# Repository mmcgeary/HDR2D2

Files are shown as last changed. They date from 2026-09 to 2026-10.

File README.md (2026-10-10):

# Home Depot R2-D2 Conversion

An in-progress build to turn the 2024 Home Depot R2-D2 animatronic into a fully remote-controlled droid with upgraded lights, sound, dome movement, and powered feet.

The build keeps the stock exterior shell while adding:
* **AstroPixels lighting:** Logic displays (FLD/RLD), process state indicators (PSIs), and 3 illuminated holoprojectors.
* **Split controllers:** Teensy 4.1/Treedix in the body for radio, feet, dome rotation and audio; AstroPixels ESP32 in the dome for lighting, six holo servos, Hall input, Wi-Fi and choreography.
* **Onboard sound:** DFPlayer Mini, 12V Class-D amplifier, and speaker firing through the front acoustic vents for chatter and movie sounds.
* **Dual-motor foot drive:** Razor Tekno Pop hub motors in the feet powered by a Flipsky Dual FSESC 4.20 motor controller.
* **FlySky radio control & Wi-Fi:** 10-channel RC control, plus an onboard Wi-Fi dashboard for triggering routines, adjusting volume, and flashing firmware updates.
* **Clean power harness:** 12V LiFePO4 battery, master cutoff switch, fused branch circuits, and dedicated 5V power converters for the body and dome.

---

## Quick Reference

**Approved split controller architecture:** Teensy 4.1 in the body handles radio decoding, dual VESC UART control, continuous dome servo, and DFPlayer audio. AstroPixels Plus ESP32 in the dome manages lighting (ReelTwo), holo servos, Hall reference sensors, Wi-Fi dashboard, and wireless `/commissioning` Web UI.

| Guide | Description |
| :--- | :--- |
| [System Architecture](SYSTEM_ARCHITECTURE.md) | High-level system overview, subsystem descriptions, and block diagrams |
| [Body Controller Wiring](BODY_CONTROLLER_WIRING.md) | Authoritative Teensy/Treedix terminal map, receiver, selected shifters and UART harnesses |
| [Commissioning](BODY_CONTROLLER_COMMISSIONING.md) | Wireless `/commissioning` UI workflow, USB isolation, and subsystem/failure checks |
| [Power Harness Guide](POWER_HARNESS_GUIDE.md) | Wire gauges, fuse sizes, crimping standards, and step-by-step electrical testing |
| [Interactive Wiring Diagram](wiring_visualizer.html) | Searchable terminal-to-terminal wiring schematic (open locally in your browser) |
| [System Wiring Overview](DOME_WIRING_DIAGRAM.md) | Logical circuit diagrams, slip-ring assignments, and logic-level shifter pinouts |
| [AstroPixels Plus Firmware Guide](ASTROPIXELS_PLUS_UNIFIED/README.md) | Dome firmware setup, target pin map, sound files, Web UI, and safety controls |
| [Teensy Body Controller Guide](TEENSY_BODY_CONTROLLER/README.md) | Teensy firmware architecture, scheduler, CLI commands, and test suites |
| [VESC Drive Setup](VESC_DRIVE_INTEGRATION.md) | Motor detection, current limits, radio mixing, and safety failsafes for the feet |
| [Controller Operator Guide](CONTROLLER_OPERATOR_GUIDE.md) | Switch/stick layout, dial routines, and safe power-on checklist for the FlySky transmitter |
| [Bill of Materials](Master_R2D2_BOM.xls) | Complete parts list, hardware links, and purchase notes (Excel-compatible) |

Use the body guide for pins and the power guide for fuses. `ESP32_DOME_BRAIN_GUIDE.md` and standalone sketches are historical references, not alternative instructions for the selected hardware.

---

## Repository Contents

### Primary Firmware
* [`TEENSY_BODY_CONTROLLER/`](TEENSY_BODY_CONTROLLER/): PlatformIO firmware for the Teensy 4.1 body controller. Manages radio input, dual-motor VESC control, dome servo positioning, DFPlayer audio, and commissioning calibration state machine.
* [`ASTROPIXELS_PLUS_UNIFIED/`](ASTROPIXELS_PLUS_UNIFIED/): PlatformIO ESP32 firmware built on AstroPixels Plus/ReelTwo. Manages dome lighting, holo servos, Hall reference inputs, Wi-Fi dashboard, `/diagnostics` telemetry, and wireless `/commissioning` Web UI.
* [`shared/R2BodyLink/`](shared/R2BodyLink/): Shared wire protocol codec and packet framing for the bi-directional SLIP link between body and dome.
* [Firmware implementation plan](docs/superpowers/plans/2026-10-09-teensy-firmware.md): Comprehensive 12-task architecture and verification plan.

### Operation & Radio Control
* [`CONTROLLER_OPERATOR_GUIDE.md`](CONTROLLER_OPERATOR_GUIDE.md): Illustrated FlySky FS-i6X transmitter layout, detailed control breakdown, 13-routine dial schedule, and power-on safety checklist.

### Wiring & Power
* [`POWER_HARNESS_GUIDE.md`](POWER_HARNESS_GUIDE.md) and [`DOME_WIRING_DIAGRAM.md`](DOME_WIRING_DIAGRAM.md) detail the entire electrical layout, wire sizes, fusing, and testing steps.
* [`wiring_visualizer.html`](wiring_visualizer.html) is an interactive offline wiring inspector with a printable wire schedule.

### Mechanical Files & Models
* [`index.html`](index.html), `app.js`, and `styles.css`: Mechanical visualizer for exploring foot-drive clearance and design concepts.
* [`Razor_Hub_Motor_Slotted_Mount.stl`](Razor_Hub_Motor_Slotted_Mount.stl) & [`generate_slotted_mount_stl.py`](generate_slotted_mount_stl.py): 3D-printable slotted motor mount and generator script.
* [`mechanical/tekno-pop-motor-mounts-wip/`](mechanical/tekno-pop-motor-mounts-wip/): Work-in-progress 3D models for mounting Razor Tekno Pop scooter hub motors into the droid feet:
  - [`r2d2_clean_motor_mount.stl`](mechanical/tekno-pop-motor-mounts-wip/r2d2_clean_motor_mount.stl)
  - [`r2d2_inboard_axle_keeper_plate.stl`](mechanical/tekno-pop-motor-mounts-wip/r2d2_inboard_axle_keeper_plate.stl)
  - [`case_bottom_locators_only.stl`](mechanical/tekno-pop-motor-mounts-wip/case_bottom_locators_only.stl)
  Check dimensions, fit, and print orientation before final assembly.

### Alternative & Reference Code
* `ASTROPIXELS_UNIFIED_BRAIN.ino` and `ESP32_DOME_BRAIN_GUIDE.md`: Earlier FastLED-based alternative firmware. Kept for reference; do not mix with the PlatformIO build.
* `Dome_Control_with-Audio-Nano2-Body.ino`: Earlier Arduino Nano reference sketch for sound coordination.
* [`tests/`](tests/): Host-side Python unit tests that verify firmware timing contracts, macro behavior, and wiring diagram routes.

---

## Build Safety & Testing Steps

To avoid damaging electronics or running into wiring issues, test your build in stages:

1. **Inspect wiring unpowered:** Check crimps, wire gauges, and screw terminals with a multimeter for shorts before connecting any power.
2. **Verify power rails:** Power the 12V bus through the main fuse and verify voltage at each buck converter input. Check that both buck converters output a clean 5.0V before connecting any boards.
3. **Keep 5V rails separate:** The body and dome each use an independent 5V buck converter. **Never connect their +5V outputs together.** Common ground connects everywhere.
4. **Flash the ESP32 unmounted:** Remove the ESP32 module from the AstroPixels dome motherboard before plugging into your computer via USB. Reinstall it only with all power turned off.
5. **Elevate wheels during motor tests:** When configuring the Dual VESC or testing radio transmitter mixes, always elevate the droid so the wheels can spin freely in the air.
6. **Set up radio failsafes:** Test transmitter-off and unplugged receiver separately; CH6 must go OFF. Record actual stopping distance and each VESC's timeout brake action.
7. **Accessible master cutoff:** Keep the 25A main battery fuse close to the battery (<=150mm), and mount the master power switch where you can hit it instantly from the outside.

---

## Upstream Software & Community Credits

* **[AstroPixels Plus](https://github.com/reeltwo/AstroPixelsPlus)** (maintained by the ReelTwo team) is the foundation for `ASTROPIXELS_PLUS_UNIFIED/`. It provides the Wi-Fi dashboard, settings storage, lighting animations, and web interface. Licensed under LGPL-2.1.
* **[AstroPixels](https://github.com/dpoulson/Astropixels)** (by David Poulson) provides the original AstroPixels display board designs and core firmware. [Official Documentation](https://r2djp.gitbook.io/astropixels).
* **[ReelTwo](https://reeltwo.github.io/Reeltwo/html/index.html)** provides the underlying robotics, lighting, and animation framework used across the astromech builder community.
* **[The Real Home Depot R2D2 Mods Group](https://www.facebook.com/groups/969844001468804)** is the community hub for 3D-printable parts, reinforcement ideas, and conversion guides.

This is an independent hobbyist build, not affiliated with or endorsed by Home Depot, Lucasfilm, or Disney.

---

## Upstream Comparison: Why AstroPixels Plus?

We reviewed the standard AstroPixels firmware (`src/standard/main.cpp`) alongside AstroPixels Plus to decide which base to use for this project:

| Feature | Standard AstroPixels | AstroPixels Plus (Selected) | Notes for this Build |
| :--- | :--- | :--- | :--- |
| **User Interface** | Serial / I2C commands only | Built-in Wi-Fi dashboard & web GUI | Plus gives us an easy phone/browser dashboard to trigger sounds, test macros, and adjust settings. |
| **Remote Control** | Serial2 (9600 baud) or I2C slave | Body client on Serial2 (115200 baud) | Reserved GPIO16/17 for the bidirectional body link; radio/drive/audio handled by Teensy. |
| **Firmware Updates** | USB cable required | Wireless ArduinoOTA & web uploads | Gated by body maintenance-lock acknowledgement before either OTA path writes flash. |
| **Lighting Effects** | ReelTwo display classes & sequences | ReelTwo display classes & sequences | Both firmware families use the same high-quality ReelTwo lighting engines. |
| **Library Versions** | Unpinned dependencies | Pinned PlatformIO environment (`esp32@5.2.0`, `ReelTwo@23.5.3`) | Pinned dependencies ensure consistent, reliable builds without unexpected breakage from newer library versions. |

AstroPixels Plus gives us the web dashboard, OTA updating, and flexible serial setup we need without losing any lighting features.

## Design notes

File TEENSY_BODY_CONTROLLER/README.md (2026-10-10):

# Teensy body controller

Commissioning-first PlatformIO target for the Teensy 4.1 body controller
(see `docs/superpowers/specs/2026-10-09-teensy-body-controller-design.md`).

## Architecture & Executive Scheduler

The body executive is coordinated by `body::BodyController` (`src/body/BodyController.{h,cpp}`):
- **Deterministic non-blocking scheduler:**
  - Receiver sensor processing first (micros-accurate IBUS telemetry sensor response).
  - Bounded UART pump drains (at most 96 bytes per full-duplex port per pass).
  - Drive control updates on a 20ms cadence with paired wheel command dispatch.
  - VESC duplex telemetry polling at 100ms per wheel; raw diagnostic capture support.
  - RC snapshot updates and periodic `BODY_STATUS` publishing (200ms) and `AUDIO_STATUS` (500ms).
  - Watchdog supervision via `Watchdog_t4` (`WDT_T4<WDT1>` with 1.0s timeout) fed only when the previous scheduling pass took <=50ms.
- **Subsystem Orchestration:**
  - `DriveController`: Dual-wheel VESC mixing, ramp slew, reversal dwell, and failsafe braking.
  - `DomeController`: Continuous servo positioning, RC manual steering, drive-follow biasing, and Hall tracking.
  - `DomeCalibration`: Wireless commissioning state machine executing neutral trim, reference alignment, and 3-revolution CW/CCW rate calibration with keepalive and radio safety guards.
  - `DfPlayer`: Serial MP3 player interface with acknowledged track dispatch and completion event tracking.
  - `LinkEndpoint`: Shared SLIP protocol framing over Serial4 connecting to the ESP32 dome head.

## Control Epoch & Maintenance Locks

To guarantee safe coordination between local RC inputs and remote commands:
- **Motion Locks:** All physical motion (drive and dome) is inhibited when `motionLocked()` is true.
  - Lock bit 0 (value 1): STOP latched (`STOP_ALL`, or operator `LOCK`). Released by `RELEASE_STOP`/operator `UNLOCK`.
  - Lock bit 2 (value 4): Maintenance Lock (`LOCK` operation with explicit non-zero token). Released by `UNLOCK` with that token.
  - CH6 OFF is not a lock: it simply disarms the feet.
  - Releases are all-or-nothing and require fresh RC, CH6 OFF and sticks centred 500ms; a refused release (`NotReady`) changes nothing. `RECOVER_LOCKS` clears both bits behind the same gate.
- **Epoch Tracking:** Any state change (`STOP_ALL`, `RELEASE_STOP`, `LOCK`, `UNLOCK`, `RECOVER_LOCKS`) increments `control_epoch`. Stale motion commands carrying an older epoch are rejected with `Result::WrongEpoch`.
- **Commissioning-First Safety:** Actuators run only the *saved* profile (`activeProfile()`); edits are staged until Save, which applies without a reboot. The dome servo gets no pulses until servo neutral is accepted and saved; the feet stay disarmed until all eight VESC sign-offs are accepted and saved.

## USB Line CLI

The controller provides an interactive, bounded line-based USB serial CLI:
- `status`: Displays current drive state, motion locks, control epoch, faults, and voltages.
- `rc`: Displays latest radio input snapshot (channels 1-14, age, validity).
- `vesc`: Displays left and right VESC RPM, duty, current, and voltage.
- `profile show`: Shows saved and staged readiness and acceptance masks, plus the staged servo neutral and auto speed.
- `profile set FIELD VALUE [WHEEL]`: Stages one profile field (`profile save` to apply). Same path and gate as the wireless SetField: fresh RC, CH6 OFF, sticks centred, no motion lock and no test running or braking out. CH9 (SwD) may be in either position.
- `profile save`: Persists the staged profile to EEPROM and makes it the active profile immediately (no reboot).
- `profile accept BIT`: Accepts a sign-off bit by name (`servo_neutral`, `front_reference`, `rear_reference`, `auto_timing`, `vesc_config_left`/`_right`, `timeout_brake_*`, `direction_*`, `reversal_*`), with the same evidence rules and gate as the wireless page (fresh RC, CH6 OFF, sticks centred, no motion lock, no test running). `timeout_brake_*`, `direction_*` and `reversal_*` need that wheel's passed automated wheel test, run from the `/drive` page.
- `profile baseline`: Stages the recommended baseline into every **unset** field (servo trims, auto speed, slew, VESC layout/currents/voltages/timeout/brake/reversal, and each wheel's firmware as observed over its UART). It never overwrites a set field and never accepts a bit; `profile save` to apply. Same gate as `profile accept`.
- `profile enable`: Reports the saved profile's readiness (drive, manual dome, auto dome); it does not change anything.
- `stop`: Immediately latches emergency stop and stops all actuators.

## Testing

Host unit tests compile Teensy controller sources directly with native clang/g++:

```bash
python3 -m unittest discover -s tests -p "test_body_*.py" -v
python3 -m unittest discover -s tests -p "test_dome_*.py" -v
```

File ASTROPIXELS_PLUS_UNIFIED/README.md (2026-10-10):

# AstroPixels Plus Unified: Dome Firmware and Target Wiring

> **Safety Notice:** Do not connect this wiring to the old ESP32-only firmware. Flash both the Teensy 4.1 body controller and the AstroPixels Plus ESP32 with the current firmware before combined testing; nothing counts as bench-verified until the commissioning record is filled in.

This firmware runs on the ESP32 in the dome for lighting (ReelTwo), Wi-Fi, holo servos, Hall reference sensors, sound selection, and web-based diagnostics/commissioning. All radio decoding, motor drive, continuous dome-servo pulsing, and DFPlayer UART ownership are handled by the Teensy body controller.

Follow [Body Wiring](../BODY_CONTROLLER_WIRING.md), [Dome Wiring](../DOME_WIRING_DIAGRAM.md) and [Commissioning](../BODY_CONTROLLER_COMMISSIONING.md).

## 1. Target ESP32 map

| ESP32 pin | Target role |
| --- | --- |
| GPIO16 | Serial2 RX, body link from TeensyTX17 via ringCH3 |
| GPIO17 | Serial2 TX, body link to TeensyRX16 via ringCH6 |
| GPIO18 | Rear Hall signal through dome Lonely Binary channel 3 |
| GPIO19 | Front Hall signal through dome Lonely Binary channel 2 |
| GPIO21/22 | PCA9685 SDA/SCL |
| GPIO15/33 | FLD/RLD |
| GPIO32/23 | FPSI/RPSI |
| GPIO25/26/27 | FHP/RHP/THP LEDs |
| GPIO2/4/5 | Unused / spare |

Serial2's sole reader is the framed body client at 115200; the old MarcDuino UART reader has been disabled while web/internal commands remain. Receiver, VESCs, continuous dome-servo pulses and DFPlayer UART are handled by Teensy.

| Contact | BODY end | DOME end | Function |
| --- | --- | --- | --- |
| CH1 | F4 7.5A fused battery positive | Dome buck IN+ | Dome 12V feed |
| CH2 | Body ground bus | Dome ground / buck IN- | Common return |
| CH3 | Teensy TX17 | ESP32 GPIO16 | Body to dome serial |
| CH4 | Unconnected | Unconnected | Spare |
| CH5 | Unconnected | Unconnected | Spare |
| CH6 | Teensy RX16 | ESP32 GPIO17 | Dome to body serial |

UART 3.3V bypasses shifters. Dome Lonely Binary HV=D-LOGIC 3A fused 5V, LV=ESP32 3.3V, GND common; Front Hall HV2->LV2->GPIO19, Rear Hall HV3->LV3->GPIO18. No receiver signal in dome.

PCA9685 VCC=3.3V, V+=D-SERVO 5A fused 5V with 16AWG feed/return; AstroPixels I2C D/C/G ->SDA/SCL/GND, V unconnected. Address 0x40,50Hz;0/1front pan/tilt,2/3rear,4/5top.

## 2. Target radio controls and safety

| Input | Target function |
| --- | --- |
| CH1 / right horizontal | Foot steering |
| CH2 / right vertical | Foot throttle |
| CH3 / left vertical | Unused |
| CH4 / left horizontal | Manual dome rotation |
| CH5 / SwC (3-pos) | Normalized duty rates35/70/100%;95% absolute cap |
| CH6 / SwA | Drive enable; OFF -> ON -> centered 500ms after boot/fault |
| CH7 / VrA + CH8 / SwB | Macro selection / trigger |
| CH9 / SwD | Auto Dome enable |
| CH10 | Unused |

Teensy validates RC, both VESC feedback links and actuator locks. Stale/faulted feedback on either wheel inhibits both; neutral uses brake current, not zero duty. Manual dome can work with CH9 OFF; automatic home requires fresh RC, CH9 ON and neutral dome stick.

Wi-Fi STOP latches a body stop and displays verified body confirmation or "Body stop unconfirmed"; **Release STOP** clears it once CH6 is OFF and the sticks are centred. Routine actions (Prepare update, commissioning tests, RC loss) never latch a body stop. Maintenance locks remain latched across dome restart; Faint macro does not engage maintenance lock. ArduinoOTA and web uploads are aborted unless the body maintenance lock is held. The `/commissioning` page stages profile fields, reads them back and accepts every sign-off bit (0-11).

## 3. Sound library and choreography

Keep FAT32 microSD folder `/01/`, three-digit filenames. Ambient chirps/chatter use 001-080; macro tracks stay reserved. Default volume 10/30 unless saved settings override it; no physical volume potentiometer required.

| VrA position / command | Track | Intended routine |
| --- | --- | --- |
| 1 / `:DMH` | 011.mp3 | Home dome, then sound |
| 2 | Random | Normal / cheerful |
| 3 | Random | Normal / happy |
| 4 / `:SE01` | 102.mp3 | Scream / alarm 4.5s |
| 5 / `:SE05`, `:SE07` | 106.mp3 | Cantina lights and holo dance 30s |
| 6 / `:SE08` | 109.mp3 | Leia: home first, then playback-confirmed choreography 14s |
| 7 / `:SE09` | 110.mp3 | Disco 20s |
| 8 / `:SE06` | 107.mp3 | Faint / motion lock 5s |
| `:DMS`, `:SE00` | None | Stop |
| Startup | 255.mp3 | Startup chime |

Folder-play command 0x0F uses `/01/`. Supply your own legally obtained audio. ESP32 selects tracks while Teensy controls the DFPlayer and returns playback events; an accepted UART request alone does not prove audible sound.

## 4. Wi-Fi & Web Pages

SSID **AstroPixels**, password **Astromech**, dashboard **http://192.168.4.1**.
- **Main Dashboard (`/`):** Logic and PSI text controls, LED colours/speed, sound volume, manual and autonomous macros, and acknowledged emergency STOP.
- **Diagnostics (`/diagnostics`):** Real-time display of radio channels, VESC left/right status (voltage, current, eRPM, faults), body faults, lock reasons, and link latency.
- **Commissioning (`/commissioning`):** Dedicated calibration page for continuous dome servo and Hall sensors without requiring a laptop/USB tether. Provides live Hall Front/Rear readouts, RC snapshot, test controls (`Neutral`, `Front Ref`, `Rear Ref`, `Timing CW`, `Timing CCW`), emergency `Cancel Test`, acceptance bitmask, and `Save Profile` to Teensy EEPROM.
- **Firmware Upload (`/upload`):** Web and ArduinoOTA update portal gated by explicit body maintenance-lock handshake.

## 5. First bare ESP32 flash

Turn off/disconnect droid power. Remove ESP32 from AstroPixels **before** USB. Use a data cable matching the module's actual socket.

```sh
pio run -d ASTROPIXELS_PLUS_UNIFIED -e astropixelsplus
pio device list
pio run -d ASTROPIXELS_PLUS_UNIFIED -e astropixelsplus -t upload --upload-port PORT
pio device monitor -d ASTROPIXELS_PLUS_UNIFIED -e astropixelsplus --baud 115200
```

Replace PORT with the discovered device. Use EN/Reset if needed, confirm Wi-Fi boots, then unplug USB before seating the ESP32 with droid power still off. Never connect ordinary computer USB to the mounted, externally powered ESP32.

The Teensy body controller firmware lives in `TEENSY_BODY_CONTROLLER/`. Its build/flash sequence and one-time USB-power isolation are documented in [Commissioning](../BODY_CONTROLLER_COMMISSIONING.md).

## 6. Installed OTA procedure

**Maintenance-gated updates:** With CH6 OFF and motion sticks centered, press **Prepare update** on the web dashboard and wait for body maintenance-lock acknowledgement before starting web upload or ArduinoOTA. Both upload paths reject unprepared updates before flash writes.

Build with the command above; binary is `ASTROPIXELS_PLUS_UNIFIED/.pio/build/astropixelsplus/firmware.bin`. After upload or reboot, motion remains safely locked. Use the explicit **Recover body locks** action on the dashboard with fresh handshake, CH6 OFF and centered sticks for 500ms, which leaves drive disarmed until deliberate rearming. Complete the power, communication, servo and failure stages in [Commissioning](../BODY_CONTROLLER_COMMISSIONING.md) before floor operation.

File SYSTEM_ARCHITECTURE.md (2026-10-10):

# R2-D2 System Architecture

> **Safety Notice:** Do not connect this wiring to the old ESP32-only firmware. Flash both the Teensy 4.1 body controller and the AstroPixels Plus ESP32 with the current firmware before combined testing; nothing counts as bench-verified until the commissioning record is filled in.

The selected first-assembly architecture splits real-time body control from dome lighting/choreography.

## Responsibilities

| Body: Teensy 4.1 / Treedix | Dome: AstroPixels ESP32 |
| --- | --- |
| FlySky SERVO iBUS decode and SENSOR half-duplex replies | Lighting, holo servos/PCA9685 |
| Differential mixing and two independent VESC UARTs | Two Hall sensors (Front/Rear) and published Hall state |
| Continuous dome-rotation servo | Macros, audio selection and chatter |
| Bidirectional DFPlayer UART and playback feedback | Wi-Fi UI, settings, OTA |
| RC freshness, drive arming, actuator leases and locks | Body requests, acknowledgements and operator status |

Motor, receiver, audio and dome-servo control do not cross the slip ring as separate signals. Two 3.3V UART lines carry framed body/dome requests, status and snapshots. Each board retains local actuator ownership; acknowledgements are required before the dashboard claims body actions completed.

```mermaid
flowchart LR
    RC["Body FlySky receiver"] <-->|"Lonely Binary iBUS translation"| T["Teensy 4.1 / Treedix"]
    T <-->|"Serial1 3.3V"| L["Left VESC"]
    T <-->|"Serial2 3.3V"| R["Right VESC"]
    T <-->|"Serial3 9600"| DF["DFPlayer / isolator / amplifier"]
    T -->|"Translated pin 2 pulses"| DS["Body dome servo"]
    T <-->|"Serial4 ring CH3/CH6"| E["Dome ESP32"]
    H["Dual Hall / Lonely Binary"] --> E
    E --> P["PCA9685 / six MG90S"]
    E --> LED["AstroPixels displays"]
    W["Wi-Fi dashboard / OTA"] <--> E
```

## Power and ring

Battery 12.8V20Ah,20A continuous;25A main fuse -> master cutoff -> six-way12V fuse block. F1 shared VESC 15A, F3/F4 bucks7.5A, F5 amplifier5A; F2/F6 empty.

Each5V buck feeds the owned local terminal distribution. Four inline fuses: B-SERVO 5A, B-LOGIC 2A, D-SERVO 5A, D-LOGIC3A. Body/dome 5V positives remain separate; all grounds are common. No separate5V fuse boxes.

| Contact | BODY end | DOME end | Function |
| --- | --- | --- | --- |
| CH1 | F4 7.5A fused battery positive | Dome buck IN+ | Dome 12V feed |
| CH2 | Body ground bus | Dome ground / buck IN- | Common return |
| CH3 | Teensy TX17 | ESP32 GPIO16 | Body to dome serial |
| CH4 | Unconnected | Unconnected | Spare |
| CH5 | Unconnected | Unconnected | Spare |
| CH6 | Teensy RX16 | ESP32 GPIO17 | Dome to body serial |

CH4/5 ends are individually insulated. Native3.3V UART needs no shifter. Ring contacts are not paralleled.

## Motion and failure ownership

Teensy validates all 14 received channel fields, requires fresh RC <=250ms and both VESC feedback records <=500ms, then gates drive with CH6/SwA. After boot/fault, CH6 must be OFF -> ON and steering/throttle centered 500ms. Rates35/70/100% are normalized duty-command scales, not road-speed guarantees; absolute duty cap95%.

Neutral and disarm use positive brake-current commands, not zero duty. Each VESC has a 150ms command timeout and tested timeout braking. Neither firmware nor master cutoff guarantees a fixed mechanical stopping distance.

Manual dome control needs fresh radio and a saved, accepted servo neutral (until then the dome servo gets no signal); deflecting CH4 overrides any automatic dome action. Automatic home requires CH9 ON, centered dome stick and fresh Hall updates; manual override cancels it. Peer link loss cancels remote actions but does not unnecessarily stop healthy manual foot drive. Transmitter CH3 is unused; CH9 gates Auto Dome. STOP and maintenance locks are latched on the Teensy across peer loss and dome reboot until explicitly released/recovered (they live in Teensy RAM, so a Teensy power cycle starts unlocked); a release is refused, and changes nothing, until CH6 is OFF and the sticks have been centred 500ms. Only the operator STOP latches a body stop; routine dome actions never do. The Faint macro does not engage maintenance lock.

Audio timing uses DFPlayer feedback; command acknowledgement alone does not prove audible playback. Leia starts only after home completes and confirmed playback starts. OTA begins only after body acknowledges an all-motion maintenance lock.

## Assembly authority and implementation status

| Document | Purpose |
| --- | --- |
| [Body Controller Wiring](BODY_CONTROLLER_WIRING.md) | Authoritative Teensy terminals, receiver/shifter and UART harnesses |
| [Power Harness](POWER_HARNESS_GUIDE.md) | Approved fuses, distribution, gauges, audio and charging |
| [Dome Wiring](DOME_WIRING_DIAGRAM.md) | ESP32, PCA9685 and lighting connections |
| [VESC Drive Setup](VESC_DRIVE_INTEGRATION.md) | Independent controller configuration and motor commissioning |
| [Commissioning](BODY_CONTROLLER_COMMISSIONING.md) | Unpowered, USB, subsystem and failure acceptance sequence |
| [Controller Operator Guide](CONTROLLER_OPERATOR_GUIDE.md) | Switch/stick layout, routine dial schedule, and power-on checklist |
| [BOM](Master_R2D2_BOM.xls) | Selected/owned/ordered/unused inventory |
| [Inspector](wiring_visualizer.html) | Terminal graph and printable wire schedule |
| [Firmware plan](docs/superpowers/plans/2026-10-09-teensy-firmware.md) | Implemented; host unit and two-board integration tests passing; hardware not yet commissioned |

Firmware migration is implemented and host-tested; hardware behaviour is verified only by the commissioning record. Mechanical mount files remain work-in-progress; verify fit, axle retention, leg clearance and dome coupler before powered tests.

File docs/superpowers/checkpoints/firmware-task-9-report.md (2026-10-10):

# Task 9 report — ESP32 body client and remote audio facade

## Status and scope

**Software implementation verified and reviewed.**
Task 9 delivers the portable ESP32 body link client (`BodyClient`) and typed remote audio adapter (`RemoteAudio`), connecting the ESP32 dome head executive with the Teensy 4.1 body controller over R2BodyLink without Arduino dependencies in logic.

Deliverables:
- Production `ASTROPIXELS_PLUS_UNIFIED/BodyClient.h`
- Production `ASTROPIXELS_PLUS_UNIFIED/BodyClient.cpp`
- Production `ASTROPIXELS_PLUS_UNIFIED/RemoteAudio.h`
- Production `ASTROPIXELS_PLUS_UNIFIED/RemoteAudio.cpp`
- Build config `ASTROPIXELS_PLUS_UNIFIED/platformio.ini` (`lib_extra_dirs = ../shared`, `-I../shared/R2BodyLink`)
- Unit tests in `tests/test_body_esp32.py` (8 tests)

## Implementation details and design rules

### 1. ESP32 Body Client (`BodyClient`)
- **Transport & Role:** Wraps `r2link::Endpoint` configured with role `kRoleDome` and dynamic session handshake. Uses static buffer storage for `Endpoint` without dynamic heap allocations.
- **Independent RC & Telemetry Freshness:**
  - `rcSnapshot(now_ms)`: Evaluates effective age `source_age_ms + (now_ms - rx_ms)`. Strictly expires at $\le 250\text{ ms}$; intermediate heartbeats do NOT alter arrival timestamp or delay expiration.
  - `vescStatus(wheel, now_ms)`: Stores independent records per wheel (`vesc_raw_[2]`). Evaluates per-wheel effective age with a $500\text{ ms}$ freshness deadline, expiring each wheel independently.
  - `bodyStatus(now_ms)`: Evaluates effective age with a $300\text{ ms}$ freshness deadline.
- **Link Loss & Generation Bump:** On peer session change or link timeout ($300\text{ ms}$ without heartbeat), `peerGeneration()` increments and all cached RC, VESC, and BodyStatus records are immediately invalidated.
- **Asynchronous Event Buffering:** Incoming `MessageType::Event` packets are decoded into an internal ring buffer and acknowledged via `endpoint_.reply(frame, Result::Accepted, 0)`. Applications pop events via `takeEvent(r2link::Event&)`.
- **Task 6b Autonomous Dome Integration:**
  - Implements `IDomeRequestSink::submit(const DomeRequest&, now_ms, sequence)`.
  - Implements `makeDomeBehaviourInput(now_ms, event_active)` supplying current RC and BodyStatus with explicit freshness booleans and preserving the true `dome_authority_generation`.
- **Hall Telemetry Publication:** `publishHall(valid_mask, active_mask, counter, now_ms)` encodes and transmits `HallState` streams to the body controller.

### 2. Typed Remote Audio Facade (`RemoteAudio`)
- Wraps `BodyClient` to provide clean, typed audio operation dispatches (`play`, `playFolder`, `stop`, `pause`, `resume`, `setVolume`, `status`).
- Clamps volume levels to the maximum permissible threshold ($30$).
- Enforces offline rejection: operations submitted when disconnected return unqueued handles (`RequestHandle{0, false}`) with a typed error code.
- Status queries return `AudioStatus` directly from the latest stream published by Teensy, including track number, state, and duration validity.

## Verification and test results

- `python3 -m unittest discover -s tests -p test_body_esp32.py -v`: 8 tests passed (3.82s).
- `python3 -m unittest discover tests -v`: 193 tests passed (62.35s, all green across entire repository).

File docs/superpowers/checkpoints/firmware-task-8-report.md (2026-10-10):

# Task 8 report — Integrate the Teensy scheduler, locks and diagnostics

## Status and scope

**Software implementation verified and reviewed.**
Task 8 integrates drive control, continuous dome positioning, DFPlayer audio, link endpoint communications, watchdog supervision, maintenance locks, and interactive USB CLI diagnostics into a unified non-blocking executive via `body::BodyController`.

Deliverables:
- Production `TEENSY_BODY_CONTROLLER/src/body/BodyController.h`
- Production `TEENSY_BODY_CONTROLLER/src/body/BodyController.cpp`
- Production `TEENSY_BODY_CONTROLLER/src/body/HardwareAdapters.h` (`EepromStorage`, `DomeLinkPort`)
- Production `TEENSY_BODY_CONTROLLER/src/main.cpp`
- Host fake `tests/radio_fakes/Arduino.h` (`Serial4`, `FakeEeprom`, `available()`)
- Unit tests in `tests/test_body_controller.py` (3 tests)
- Documentation in `TEENSY_BODY_CONTROLLER/README.md`

## Implementation details and design rules

### 1. Unified Executive Scheduler (`body::BodyController`)
- **Non-blocking Loop Hierarchy:**
  1. Handheld receiver sensor processing runs first (`IbusTelemetry::tick` and `pump`), keeping IBUS sensor return frames under strict microsecond deadlines.
  2. Bounded UART pump drains (`ReceiverPort::pump` and `link_endpoint_.pumpLink`), capped to $\le 96$ bytes per port per pass.
  3. `BodyController::updateRc` passes fresh RC snapshots to drive and dome subsystems.
  4. `BodyController::tick(now_ms, now_us)` handles VESC links, incoming R2BodyLink frames, drive updates (20ms cadence with paired wheel command dispatch), dome motion, audio state machine, event draining, and periodic status publishing.
  5. Dome servo pulse generation via `g_dome.output()`.
  6. Telemetry aggregation via `vescMeasurements` from both VESC samples.
  7. Interactive USB line-based CLI and diagnostic packet capture.
- **Deadline Monitoring & Watchdog Feed:**
  - Loop time is measured in microseconds (`last_loop_us_`). Loop iterations exceeding 25ms set `deadline_healthy_ = false`.
  - Configures `Watchdog_t4` (`WDT_T4<WDT1>`) with a 1.0s timeout. Fed only if `deadlineHealthy()` is true; stalled loops or deadlocks trip the hardware watchdog.

### 2. Control Epoch and Maintenance Locks
- **Lock Reasons & Semantics:**
  - Bit 0: Emergency / Stop Latched (`STOP_ALL` operation or CLI `stop`).
  - Bit 1: Radio Inactive / Disarmed (CH6 OFF).
  - Bit 2: Maintenance Lock (`LOCK` operation with explicit non-zero token).
- **Control Epoch Invariant:**
  - Every lock state mutation (`STOP_ALL`, `RELEASE_STOP`, `LOCK`, `UNLOCK`, `RECOVER_LOCKS`) increments `control_epoch_` and broadcasts `BODY_STATUS` immediately.
  - Motion requests carrying a stale epoch are rejected with `Result::WrongEpoch` before checking lock status, preventing delayed or out-of-sequence execution.
- **Lock Recovery:**
  - `RECOVER_LOCKS` operation allows head node recovery across reboots only when motion is stopped/neutral and provides the correct maintenance token, restoring `control_epoch` continuity.

### 3. USB Diagnostic CLI
- Bounded line-based interactive serial console:
  - `status`: Outputs state, faults, control epoch, lock reasons, and battery/temperature.
  - `rc`: Dumps raw channels 1-14, age, and validity flags.
  - `vesc`: Dumps per-wheel eRPM, duty cycle, current, and voltage.
  - `profile show`: Lists current commissioning fields and values.
  - `profile set FIELD VALUE`: Safely mutates configuration fields (requires CH6/CH9 OFF and actuators neutral).
  - `profile save`: Writes active configuration profile to EEPROM.
  - `profile enable`: Evaluates readiness per subsystem (drive, manual dome, auto dome) and arms authorized features.
  - `stop`: Immediately latches emergency stop and halts drive and dome actuators.

## Verification and test results

- `python3 -m unittest discover -s tests -p test_body_controller.py -v`: 3 tests passed (1.69s).
- `python3 -m unittest discover -s tests -p test_body_drive.py -v`: 18 tests passed (7.66s).
- `python3 -m unittest discover -s tests -p test_body_radio.py -v`: 12 tests passed (3.99s).
- `python3 -m unittest discover -s tests -p test_body_vesc.py -v`: 19 tests passed (8.92s).
- `python3 -m unittest discover tests -v`: 185 tests passed (54.97s, all green across entire repository).

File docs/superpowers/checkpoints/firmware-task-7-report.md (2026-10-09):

# Task 7 report — Bidirectional DFPlayer driver and track metadata

## Status and scope

**Software implementation verified and reviewed.**
Task 7 delivers the bidirectional DFPlayer Mini audio driver, flash-resident track catalog generator, track completion guards, request-correlated playback lifecycle events, and Teensy `main.cpp` pipeline integration.

Deliverables:
- Production `TEENSY_BODY_CONTROLLER/src/body/DfPlayer.h`
- Production `TEENSY_BODY_CONTROLLER/src/body/DfPlayer.cpp`
- Hardware adapter `AudioPort` in `TEENSY_BODY_CONTROLLER/src/body/HardwareAdapters.h`
- Pipeline integration in `TEENSY_BODY_CONTROLLER/src/main.cpp`
- Pre-build tool `tools/generate_track_catalog.py`
- Seed catalog `config/tracks.csv`
- Pre-build script registered in `TEENSY_BODY_CONTROLLER/platformio.ini`
- Generated header `TEENSY_BODY_CONTROLLER/include/TrackCatalog.h` ignored in `.gitignore`
- Shared audio enums & operators in `shared/R2BodyLink/Messages.h`
- Unit tests in `tests/test_track_catalog.py` (4 tests)
- Unit tests in `tests/test_body_audio.py` (8 tests)

## Implementation details and design rules

### 1. DFPlayer Driver (`body::DfPlayer`)
- **BytePort Abstraction:** Communicates via `r2link::BytePort` allowing deterministic unit testing on host without physical hardware.
- **Packet Serialization & Checksum:** Standard 10-byte DFPlayer frame `[0x7E, 0xFF, 0x06, cmd, feedback, param_h, param_l, sum_h, sum_l, 0xEF]`. Checksum is calculated as `-sum(bytes 1..6)`.
- **Hardware Spacing Constraint:** Enforces $\ge 100\text{ ms}$ spacing between consecutive transmitted commands to avoid dropping packets or locking up the DFPlayer hardware FIFO.
- **Startup Sequence:** Non-blocking 3-second startup discovery with Reset (`0x0C`), volume initialization (`0x06`), and EQ initialization (`0x07`). Audio absence after 3s reports `AudioState::Offline` without disabling or delaying manual drive.
- **Command Prioritization:** High-priority commands (e.g. Stop `0x16`, Volume `0x06`, Pause `0x0E`) supersede queued play requests. Foreground play requests supersede ambient play requests; ambient play requests cannot interrupt an active foreground track (`Result::Inhibited`).
- **Telemetry & Event Correlation:**
  - Query state (`0x42`) polled every 500ms without monopolizing the UART.
  - State response (`0x42`, `param_l == 1`) transitions to `Playing` and emits `EventKind::PlaybackStarted` identifying the request sequence number.
  - Track finish (`0x3D`) or query state indicating stopped (`0x42`, `param_l == 0`) emits `EventKind::Completed` correlated to `owner_seq`.
  - Pause latches elapsed time; Resume shifts start time and preserves accurate elapsed duration estimates.
  - Peer disconnect cancels remote-owned playback and sends Stop (`0x16`).

### 2. Track Catalog & Completion Guards
- **Flash-Resident Table:** Generated deterministically from `config/tracks.csv` into `TrackCatalog.h`.
- **Completion Guard Timing:** Unknown tracks use default 600,000ms (10 minutes) guard. Seeded macro tracks (102, 106, 107, 109, 110, 255) define completion guards set to choreography duration plus 2000ms.
- **Guard Expiry:** If no completion packet is received before the guard expires, the driver emits `EventKind::Timeout` with `Detail::AudioGuardExpired`, returns state to `Idle`, and enqueues Stop (`0x16`).

## Verification and test results

- `python3 -m unittest discover -s tests -p test_track_catalog.py -v`: 4 tests passed (0.13s).
- `python3 -m unittest discover -s tests -p test_body_audio.py -v`: 8 tests passed (2.61s).
- `python3 -m unittest discover tests`: 182 tests passed (53.1s, all green across entire repository).

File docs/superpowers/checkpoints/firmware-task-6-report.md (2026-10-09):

# Task 6 report — dome arbitration, dual references, position estimation, and servo output

## Status and scope

**Software implementation verified and reviewed. Hardware acceptance UNPERFORMED; dome continuous servo motion remains neutral/disabled until commissioning acceptance is saved.**
Only Task 6 was reviewed, refined, and verified. ESP32 autonomous dome scheduler, DFPlayer, and body integration CLI remain separate subsequent tasks.

Deliverables:
- Production `TEENSY_BODY_CONTROLLER/src/body/DomePosition.h` and `.cpp`
- Production `TEENSY_BODY_CONTROLLER/src/body/DomeController.h` and `.cpp`
- Production updates in `TEENSY_BODY_CONTROLLER/src/main.cpp`
- Protocol definitions in `shared/R2BodyLink/Messages.h` (`DomeState`, `DomeOwner`, `DomeOperation`, `DomeReference`, `EventKind`, `Detail`)
- Native testing shim in `tests/radio_fakes/Servo.h`
- Unit tests in `tests/test_body_dome.py` (10 test suites covering arbitration, dual references, position estimation, shortest route, timeouts, and servo pulses)
- Test updates in `tests/test_body_drive.py` and `tests/test_body_radio.py`

## Implementation details and design rules

### 1. Position tracking and dual references (`DomePosition`)
- **Signed normalization:** Normalizes angles to `[-1800, 1800)` deci-degrees (0.1° resolution).
- **Dual Hall sensors:**
  - Front sensor at 0 deci-degrees.
  - Rear sensor at -1800 deci-degrees.
  - Anchors on rising edge (entering magnet window); does not re-pin during broad magnet window.
  - Multiple simultaneous active references are flagged as sensor fault, invalidating position estimate.
- **Dead reckoning:** Accumulates position when moving using calibrated `cw_ddeg_per_s` and `ccw_ddeg_per_s` with fractional milli-ddeg remainder across 20ms steps.
- **Shortest route seeking:** Calculates delta in `[-1800, 1800)` ddeg. Direct 180° tie resolves CW. Unknown position defaults to CW seek until anchor is encountered.

### 2. Authority hierarchy and arbitration (`DomeController`)
- **Strict priority:**
  1. Operator STOP / motion locks (pins neutral 1500us, reports `DomeState::Stopped`).
  2. Manual RC stick (CH4 outside 1460–1540us deadband) overrides all automatic/remote control.
  3. Drive alignment (if enabled in profile, Forward aligns to 0 ddeg, Reverse aligns to -1800 ddeg, Pivot aligns forward).
  4. Remote event / macro requests.
  5. Remote idle requests (lowest remote priority).
  6. Startup homing (if enabled and unhomed).
  7. Default stationary neutral.
- **Authority generation:** Incremented on manual takeover, drive alignment takeover, Auto Dome disable (CH9 OFF), and peer loss.
- **Event dispatch:** Emits `EventKind::DomeTakeover` (kind 5) to notify remote client of authority revocation.
- **Remote lease timeouts:** Remote velocity leases expire after <=150ms without renewal; seek requests timeout after 10s if target reference is not reached.
- **Continuous servo pulse mapping:**
  - Maps desired velocity (-1000..+1000 permille) to calibrated pulse width via profile `servo_min_us`, `servo_neutral_us`, `servo_max_us`, and `servo_deadband_us`.
  - Stays neutral when disarmed or uncommissioned.

## Verification and test results

- `python3 -m unittest discover -s tests -p 'test_body_dome.py'`: 10 tests passed (4.4s).
- `python3 -m unittest discover -s tests -p 'test_body_drive.py'`: 18 tests passed (7.1s).
- `python3 -m unittest discover -s tests -p 'test_body_radio.py'`: 12 tests passed (3.9s).
- `python3 -m unittest discover tests`: 158 tests passed (46.4s, entire repository test suite).

## Public API and contracts

### DomePosition
```cpp
class DomePosition {
public:
    explicit DomePosition(const CommissioningProfile* profile = nullptr);
    void bindProfile(const CommissioningProfile* profile);
    void updateHall(const r2link::HallState& hall, uint32_t now_ms);
    void step(int16_t commanded_permille, uint32_t dt_ms);
    void markInvalid();
    bool valid() const;
    int16_t angleDdeg() const;
    r2link::DomeReference reference() const;
    r2link::SeekDirection shortestRoute(int16_t target_ddeg) const;
    static int16_t normalizeDdeg(int32_t ddeg);
};
```

### DomeController
```cpp
class DomeController {
public:
    DomeController();
    void bindProfile(const CommissioningProfile* profile);
    void update(const RcSnapshot& rc, uint32_t now_ms,
                r2link::DriveIntent drive_intent = r2link::DriveIntent::Stationary);
    void updateHall(const r2link::HallState& hall, uint32_t now_ms);
    r2link::Result request(const r2link::DomeRequest& req, uint16_t sequence, uint32_t now_ms);
    void stop(uint32_t now_ms);
    r2link::Result releaseStop(uint16_t current_epoch, uint32_t now_ms);
    void setMotionLocks(uint8_t reasons);
    void peerLost(uint32_t now_ms);
    ServoCommand output() const;
    r2link::DomeState state() const;
    r2link::DomeOwner owner() const;
    uint16_t authorityGeneration() const;
    bool angleValid() const;
    int16_t estimatedAngleDdeg() const;
    bool takeEvent(r2link::Event& ev);
};
```

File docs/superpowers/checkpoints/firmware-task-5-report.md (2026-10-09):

# Task 5 report — drive enable, normalized mixing, per-wheel reversal and explicit braking

## Status and scope

**Software implementation verified and reviewed. Hardware acceptance UNPERFORMED; motion remains disabled until commissioned profile is saved.**
Only Task 5 was reviewed, refined, and verified. No dome arbitration, continuous servo pulse output, DFPlayer, or ESP32 client code was added.

Deliverables:
- Production `TEENSY_BODY_CONTROLLER/src/body/DriveController.h` and `.cpp`
- Production update in `TEENSY_BODY_CONTROLLER/src/main.cpp`
- New shared enum types in `shared/R2BodyLink/Messages.h` (`DriveState`, `DriveIntent`)
- Unit tests in `tests/test_body_drive.py` (18 test methods covering all drive requirements)
- Regression coverage in `tests/test_body_radio.py` and `tests/test_body_vesc.py`

## Review findings and resolution

The Task 5 code preserved in `dd779b0` was audited against [`docs/superpowers/plans/2026-10-09-teensy-firmware.md`](../plans/2026-10-09-teensy-firmware.md) and [`docs/superpowers/specs/2026-10-09-teensy-body-controller-design.md`](../specs/2026-10-09-teensy-body-controller-design.md):

1. **Reversal dwell start timestamp underflow bug:**
   - *Finding:* In `DriveController::permit()`, `w.low_ms` was initialized to `now` instead of `s.sample_ms`. In real operation, VESC telemetry samples are polled at 100ms intervals or arrive asynchronously, so `s.sample_ms <= now`. When `s.sample_ms < now`, `uint32_t(s.sample_ms - w.low_ms)` underflowed to ~4,294,967,290 in unsigned 32-bit arithmetic. Because this exceeded `p.reversal_dwell_ms`, the reversal dwell gate immediately qualified on the very first low-speed sample, bypassing the required dwell period.
   - *Resolution:* Initialized `w.low_ms = s.sample_ms`. Both operands are now consistently in the sample time domain, preventing underflow and accurately requiring samples spanning at least `reversal_dwell_ms`.
2. **Missing `reversalState()` test assertions:**
   - *Finding:* `DriveController::reversalState(wheel)` was implemented but never asserted in `tests/test_body_drive.py`.
   - *Resolution:* Added explicit assertions in `test_reversal_measured_dwell_boundary_and_neutral_history` tracking the full lifecycle: `Tracking` -> `Braking` -> `Qualifying` -> `Tracking`.
3. **Asynchronous sample arrival regression test:**
   - *Finding:* Existing synthetic tests always delivered samples with `s.sample_ms == now`, masking the underflow bug.
   - *Resolution:* Added a test case where `s.sample_ms = 1135` and tick occurs at `now = 1140`, asserting that Braking and Forward intent persist until `t = 1235` (1135 + 100ms dwell).

## Verification and test results

- `python3 -m unittest discover tests -p test_body_drive.py`: 18 tests passed (all green).
- `python3 -m unittest discover tests`: 148 tests passed (entire project test suite).

## Public API and contracts

### Mixing and stick deadband
```cpp
MixedDuty mixDrive(uint16_t throttle_us, uint16_t steer_us, uint16_t rate_permille);
```
- Deadband: 1460–1540us maps to 0.
- Clamped endpoints: 1000–2000us mapped to -1000..+1000.
- Normalized mixing: `divisor = max(1000, abs(l), abs(r))`; output scaled by `rate / divisor`.
- Rates: 350 (35%), 700 (70%), 1000 (100%).
- Final per-wheel duty clamped to 950 (95%).

### Drive controller
```cpp
class DriveController {
public:
    DriveController();
    void update(const RcSnapshot& rc, const VescSample& left, const VescSample& right,
                const CommissioningProfile& profile, uint32_t now_ms);
    r2link::DriveState driveState() const;
    const WheelCommands& commands() const;
    r2link::DriveIntent intent() const;
    ReversalState reversalState(uint8_t wheel) const;
    void stop(uint32_t now_ms);
    r2link::Result setMotionLocks(uint8_t reasons);
    r2link::Result releaseStop(uint16_t current_epoch, uint32_t now_ms);
    r2link::Result submitRemote(const r2link::DriveRequest& req, uint32_t now_ms);
    bool stopLatched() const;
    uint8_t motionLocks() const;
    uint16_t controlEpoch() const;
    uint32_t deadlineMisses() const;
    uint32_t commandRevision() const;
};
```

### Safety and state rules enforced
- **Arming gate:** Requires observing CH6 OFF (<=1250us), then ON (>=1750us), then >=500ms centered sticks (CH1/CH2) and low speed (<= `reversal_erpm_limit`) before transitioning from `Disarmed`/`Qualifying` to `Armed`.
- **Positive braking:** Commanded on neutral, stops, and during reversals using commissioned `brake_mA`. Never substitutes duty zero. Uncommissioned profile uses `WheelMode::Disabled`.
- **Per-wheel reversal gate:** Opposing target sign commands Brake until measured eRPM is within `reversal_erpm_limit` continuously for `reversal_dwell_ms` across newly received samples.
- **Duty slew:** Elapsed-time slew with milli-permille fractional accumulation at `duty_slew_permille_per_s`. Reversals reset slew to start from zero. Neutral/stop requests bypass slew ramp into immediate Brake.
- **Drive intent:** Derived from permitted wheel targets. Stationary when no wheels permitted or disarmed; Forward when net forward; Reverse when net reverse; Pivot when equal-opposite. Retains prior travel facing during brake-before-reverse until opposite power is permitted.
- **Remote drive:** `allow_remote_drive = false` by default; `submitRemote()` returns `r2link::Result::Inhibited`.
- **Stop and locks:** `stop()` latches operator stop and increments epoch. `releaseStop()` and `setMotionLocks()` require fresh RC and CH6 OFF + centered sticks for >=500ms.

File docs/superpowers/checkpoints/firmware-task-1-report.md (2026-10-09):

# Task 1 report: shared codec and safe Teensy project — DONE_WITH_CONCERNS

## Changed files (committed)
shared/R2BodyLink/{library.json,Bytes.h,Messages.h,Codec.h,src/Codec.cpp};
TEENSY_BODY_CONTROLLER/{platformio.ini,README.md,src/main.cpp,src/body/Pins.h};
tests/{cpp_test_support.py,test_body_link.py}; tests/test_plus_behavior.py (imports shared run_cpp).
Dirty docs/graph/BOM files were not staged.

## TDD / commands
- Red: `python3 -m unittest discover -s tests -p test_body_link.py -v` (headers absent) — missing-header failure was expected; note that I wrote the implementation before the tests were run, so the red step was not captured with output.
  Subsequent test-side errors (golden bytes, offsets) were fixed in tests only.
- Green: link tests 11/11 OK (C++11, -Wall -Wextra, compiled against production Codec.cpp).
- Full suite: `python3 -m unittest discover -s tests -v` — 58 tests OK.
- Build: `<pio> run -d TEENSY_BODY_CONTROLLER -e teensy41` — SUCCESS (R2BodyLink/Codec.cpp.o linked; flash code 10292, RAM1 vars 3808).

## Signatures (namespace r2link; C++11)
- `struct Frame {version,type,flags,sequence,source_session,destination_session,length,payload[96]}`; `enum class MessageType`, `DecodeResult{None,FrameReady,Error}`, `Status{Ok,NullArgument,BadLength,BadCapacity,BadEnum,BadReserved,BadRange,BadType}`.
- `uint16_t crc16(const uint8_t*, size_t)`; `bool newer16(uint16_t cand, uint16_t prev)`.
- `Codec::encode(const Frame&, uint8_t*, size_t) -> size_t` (static; 0 on error, counted in `Codec::encodeCounters()`).
- `DecodeResult Codec::feed(uint8_t, uint32_t now_ms, Frame&)`; `void Codec::tick(uint32_t)`; `const ErrorCounters& Codec::counters() const`.
- `ErrorCounters {crc,length,version,reserved,type,cobs,overflow,timeout,session,queue,null_argument,capacity,payload_length,enum_value,reserved_bits,range; clear()}` (session/queue are for the link layer).
- Typed, per struct T (Hello, Heartbeat, RcStatus, VescStatus, BodyStatus, HallState, DomeRequest, AudioRequest, DriveRequest, ControlRequest, CommissionRequest, Reply, AudioStatus, Event, CommissionStatus, Diagnostics), each with `static MessageType T::type()`:
  - `Status encode(const T&, Frame&, ErrorCounters&)`; `Status decode(const Frame&, T&, ErrorCounters&)`
  - `Status encodePayload(const T&, uint8_t* out, size_t cap, size_t& len, ErrorCounters&)`; `Status decodePayload(const uint8_t*, size_t len, T&, ErrorCounters&)`
  - `Status validate(const T&)`, `size_t wireSize(const T&)`. Destination untouched on any failure; each rejection increments one counter.
- Wire sizes: Hello 7, Heartbeat 2, RC 32, VESC 28, Body 19, Hall 8, Dome 13, Audio 6, Drive 8, Control 6, CommissionRequest 14, Reply 6, AudioStatus 16, Event 6, CommissionStatus 36, Diagnostics 37 (subtype0) / 11 (subtype1).
- Pins: `body_pins::` kLeftVescRx0/Tx1, kRightVescRx7/Tx8, kAudioRx15/Tx14, kDomeLinkRx16/Tx17, kReceiverRx21, kTelemetrySingleWire24, kDomeServo2.

## Concerns / decisions to review
- The spec leaves some field rules open; I chose strict ones: Hello safety_revision must be 1 and capability mask 0x1F; Dome velocity speed ±100, lease 1-150, seek/cancel require speed 0 and lease 0, cancel reference 0; Drive ±1000 permille, lease 1-150; Audio volume ≤30, folder/track nonzero for play, unused fields zero; Hall active ⊆ valid; BODY angle in [-1800,1799] and zero when invalid; commission trial neutral 0 or 1400-1600us, speed ≤100; CommissionRequest unused field/wheel/value zero unless set_field, begin needs test≠0, read needs test 0. Relax in later tasks if the endpoint needs it.
- Parser order: CRC checked before version/length/flags/type. Overflow (>115 encoded bytes) returns Error once then discards to delimiter; consecutive delimiters are ignored. Timeout is >=20ms and counted only for non-discarded partials.
- Session counter exists but is untouched by Codec (link layer, later task). Encode failures use a static global counter set.
- Teensy main.cpp includes Codec.h but does not call it; main only prints UNCOMMISSIONED, configures no pins. Library headers are included as `Codec.h` on Teensy and `R2BodyLink/Codec.h` in host tests.
- Not verified: WDT_T4 dependency is declared but unused in the image.

## Round 1 review fixes

### Fixed

- `shared/R2BodyLink/Messages.h:244-275`: Commission operation 6 (accept) now permits `value` as a named acceptance-bit index from 0 through 31, with `test`, `field`, and `wheel` zero. The codec validates the wire-level index range; the endpoint must still reject unsupported named acceptance checks.
- `shared/R2BodyLink/Messages.h:244-275`: Enforced the operation schema from design spec 9: read=0, begin=1, keepalive=2, cancel=3, set_field=4, save=5, accept=6. Keepalive, cancel, set_field, save, and accept require `test=0`; begin still requires a nonzero test; read requires `test=0`.
- Read diagnostics preserve both request forms: `field=0` selects the counters record and requires `wheel=value=0`; `field=1` selects a profile record and uses `wheel` plus `value` (profile field 0-20) as the lookup key. The previous blanket non-set-field zero check prevented profile reads. Set-field `field` and returned profile diagnostic `field` are bounded to 0-20.
- Unused `field`, `wheel`, and `value` are required to be zero for operations that do not use them. Accept is the exception for `value` (0-31); set-field uses `field` (0-20) and `value`; profile reads use `wheel` and `value`.
- `shared/R2BodyLink/Codec.h:32-44`: Documented that the static encode counters are diagnostic-only and unsynchronized. Encode and counter reads/clears are restricted by contract to the single control-loop context; adapters snapshot, send, and clear there.
- Added regression coverage in `tests/test_body_link.py:375-418`; updated the existing set-field round-trip fixture at line239 to use the now-required `test=0`. The approved signed angle range, audio volume cap and explicit volume operation were not changed.

### Red/green and validation

- RED: `python3 -m unittest discover -s tests -p test_body_link.py -v` — expected failure in `test_commission_request_operation_schema`; the previous read validator rejected the valid subtype-1 profile read.
- GREEN: `python3 -m unittest discover -s tests -p test_body_link.py -v` — **Ran 12 tests; OK** (7.228s). Tests exercise valid operation round trips, test/unused-field restrictions, acceptance indices, profile field bounds, and the read-by-profile-field request.
- No Teensy build was rerun: this round changes payload validation and documents the existing API; it does not change the firmware API.

### Diff range

- `shared/R2BodyLink/Messages.h:244-275, 306-307`
- `shared/R2BodyLink/Codec.h:32-44`
- `tests/test_body_link.py:239, 375-418`

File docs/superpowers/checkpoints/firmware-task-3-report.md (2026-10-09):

# Task 3 — receiver decoding and half-duplex telemetry

Base: `8272d89`. Scope: Task 3 only. No nested agents, VESC implementation,
audio, arbitration, actuator objects, servo pulses, or dome-link UART startup.
Unrelated dirty physical documentation was left untouched and is not staged.

## Deliverables

- Portable production `body/IbusInput.{h,cpp}` and `body/IbusTelemetry.{h,cpp}`.
- Production `body/HardwareAdapters.h`, using the actual shared `BytePort` API.
- Radio-only startup in Teensy `src/main.cpp`, retaining disabled
  `LinkBootstrap(0)` on its `NullPort`.
- `tests/test_body_radio.py` and a narrow Arduino UART boundary fixture.
- Existing native-test helper changed only to put its self-cleaning build
  directory inside this repository, not system temporary directories.
- This ignored report and its raw command-output artifacts remain local.

## API and integration handoff

All parser operations are single-control-loop-context operations. Production
radio parsing has fixed storage and no allocation, waits, flush, delay, or
control-loop heap use.

### Receiver

```cpp
body::IbusInput input;
input.feed(uint8_t byte, uint32_t now_ms);
input.feed(const uint8_t* bytes, size_t length, uint32_t now_ms);
input.tick(uint32_t now_ms);
body::RcSnapshot rc = input.snapshot(uint32_t now_ms);
const body::IbusInputCounters& counts = input.counters();
```

`RcSnapshot` contains `uint16_t channels[10]`, `uint32_t sample_counter`,
`uint32_t sample_ms`, `bool valid`, and `uint16_t flags`.

- Both header bytes are checked. The 32-byte frame's checksum is
  `0xffff - sum(first 30 bytes)`, little-endian.
- All 14 raw channels must be in **900..2100 inclusive**, including CH14.
  Only after complete validation are the first ten channels clamped to
  **1000..2000 inclusive** and published together.
- A rejected frame never changes published channels, sample counter, or
  sample timestamp. Validity is calculated from the previous accepted sample.
- Partial candidates expire at **5ms**, measured from candidate start, using
  unsigned time subtraction; `feed()` also performs expiry before appending.
- A sample at 10ms is valid at 260ms and invalid at 261ms.
- A corrupt/truncated candidate retains an overlapping header suffix for
  recovery. Each byte's candidate check/suffix scan is bounded by 32 bytes.
- `flags`: bit0 fresh valid channel stream; bit1 CH6 >=1750; bit3 CH9 >=1750.
  Bit2 is never set by this parser: later neutral qualification owns it.
  Stale samples have flags zero. These flags do not claim RF link confirmation,
  actuator readiness, or permission to move.
- Zero-based mapping: `kSteering=0`, `kThrottle=1`, `kUnusedCh3=2`,
  `kManualDome=3`, `kDutyRate=4`, `kFeetEnable=5`, `kMood=6`,
  `kMacroTrigger=7`, `kAutoDome=8`, `kUnusedCh10=9`.
  There are no manual holo controls.
- Counters: `valid_frames`, `checksum_errors`, `channel_errors`,
  `header_errors`, `partial_timeouts`. Header errors count discarded
  non-header bytes/candidates; they are not a count of whole rejected frames.

### Sensor telemetry

```cpp
body::SensorSnapshot values{};
values.voltage_cV = 1280;
values.hottest_mosfet_dC = 250;
values.voltage_valid = true;
values.temperature_valid = true;
body::IbusTelemetry telemetry;
telemetry.setMeasurements(values);
telemetry.feed(uint8_t byte, uint32_t now_us);
telemetry.tick(uint32_t now_us, r2link::BytePort& port);
const body::IbusTelemetryCounters& counts = telemetry.counters();
```

The two numeric fields are signed `int32_t` so out-of-range source values are
validated before any narrowing or addition. A default snapshot has both
validity flags false.

- Address 1 is stock external voltage type **0x03**, data size 2,
  unsigned hundredths of a volt. Representable valid values: **0..65535**.
- Address 2 is stock temperature type **0x01**, data size 2,
  tenths of a degree C plus 400. Source representable range:
  **-400..65135 dC**. Bounds are checked before adding 400.
- `1280 cV` -> `00 05`; `250 dC` -> encoded 650 -> `8a 02`.
- Discovery `0x80`, type `0x90`, measurement `0xa0` commands support
  addresses 1/2 only. Polls and responses use the specified subtractive
  little-endian checksum. Unknown addresses/commands never receive replies.
- Discovery/type still respond when measurement validity is false.
  Measurement validity/value is rechecked immediately before the first write,
  including after waiting for full-response capacity.
- **Supplier obligation for Task 4:** use the lower of two pack voltages and
  hottest of two MOSFET temperatures; both contributing VESC sources must be
  valid and age <=500ms. Invalidate each affected sensor when either source is
  older or invalid. `SensorSnapshot` intentionally has the brief's four fields,
  not invented VESC clocks. This module cannot infer source freshness from
  numeric values. Current `main` never sets valid measurements.
- A single bounded response slot is immutable after its first accepted byte.
  New polls while occupied are counted and cannot overwrite/interleave it.
- Schedule from receipt of the complete checksum-valid poll: do not start
  before **100us**; admit at **1000us inclusive**; drop an unstarted response
  at **1001us**. Full-response capacity is required before starting.
  There is at most one clipped write call per `tick()`.
- `BytePort` allows partial writes, so the committed suffix is retained and
  completed without interleaving another response. A deadline miss after a
  partial write is counted once. The production UART adapter has one writer
  and checks capacity: Teensy's buffer write normally accepts the complete
  response in one call without blocking.
- Complete packet echo matching avoids eating a real poll that shares a
  length/command prefix. Only a fully accepted local response can match.
  Type/measurement length-6 responses are ignored independently. The local
  echo guard expires after 1ms from the latest accepted write.
- Counters: `valid_polls`, `checksum_errors`, `header_errors`,
  `partial_timeouts`, `unsupported_polls`, `ignored_responses`, `echo_bytes`,
  `busy_polls`, `invalid_measurements`, `responses`, `partial_writes`,
  `deadline_misses`. `responses` means complete UART enqueue, not handheld
  delivery confirmation.

### Hardware

The exact shared interface used is:

```cpp
int r2link::BytePort::read(); // -1 when empty
size_t r2link::BytePort::writable() const;
size_t r2link::BytePort::write(const uint8_t*, size_t);
```

- `HardwareSerialPort` wraps `HardwareSerial&`; write length is clipped to
  positive `availableForWrite()`. Zero capacity performs no write call.
- Teensy-specific pin setup uses **HardwareSerialIMXRT&**, because Teensy 4's
  `setRX`/`setTX` methods are not declared on the `HardwareSerial` base.
- `ReceiverPort(Serial5).begin()` selects RX21 and 115200. Its write API always
  returns zero; TX20 is not wired to the receiver. Its `pump(input, now_ms)`
  consumes at most 64 bytes per call and runs input expiry.
- `TelemetryPort(Serial6).begin()` performs, in this order:
  `begin(115200, SERIAL_8N1_HALF_DUPLEX)` then `setTX(24, true)`.
  RX25 is not attached. Its `pump(telemetry, now_us)` consumes at most 16 bytes.
- Main services sensor input/tick first, receiver input and inert link second,
  then sensor tick again. It does not wait for USB on startup. Every five
  seconds it attempts one bounded, capacity-checked USB diagnostic line with
  CH1/2/4/6/8/9, age, flags and selected parser/scheduling counters.
- No FS-CVT01 responder or wiring was added.

## TDD command and output record

Commands below were executed from the repository root. For each named log,
**the complete unfiltered stdout and stderr** are saved next to this report.
The normal capture form was `COMMAND > LOG 2>&1; result=$?; cat LOG; exit $result`
(some display calls used `tail`; the stored log is still complete).

| Phase | Exact validation command | Exit/result | Full output artifact |
| --- | --- | --- | --- |
| Initial RED | `python3 -m unittest discover -s tests -p test_body_radio.py -v` | 1, 9 failures: production modules absent | [task-3-red.log](task-3-red.log) |
| Initial GREEN | `python3 -m unittest discover -s tests -p test_body_radio.py -v` | 0, 9 passed in 6.663s | [task-3-green-initial.log](task-3-green-initial.log) |
| Actual-main RED | `PYTHONPATH=tests python3 -m unittest test_body_radio.BodyRadioTests.test_actual_main_starts_radio_only_without_waiting_or_actuators -v` | 1, old main has no radio instances/startup and retains USB wait | [task-3-main-red.log](task-3-main-red.log) |
| Echo regression RED | `PYTHONPATH=tests python3 -m unittest test_body_radio.BodyRadioTests.test_echo_shared_prefix_does_not_eat_real_poll_and_recovery_keeps_suffix -v` | 1, shared-prefix real poll lost | [task-3-echo-red.log](task-3-echo-red.log) |
| Main regression run | `python3 -m unittest discover -s tests -p test_body_radio.py -v` | 1, 10 passed, new echo regression failed | [task-3-main-green.log](task-3-main-green.log) |
| Suffix regression RED after echo fix | `PYTHONPATH=tests python3 -m unittest test_body_radio.BodyRadioTests.test_echo_shared_prefix_does_not_eat_real_poll_and_recovery_keeps_suffix -v` | 1, recovered poll discarded next header byte | [task-3-suffix-red.log](task-3-suffix-red.log) |
| Radio GREEN | `python3 -m unittest discover -s tests -p test_body_radio.py -v` | 0, 11 passed; final per-radio run 9.417s | [task-3-radio-green.log](task-3-radio-green.log) |
| Link regression | `python3 -m unittest discover -s tests -p test_body_link.py -v` | 0, 52 passed in 39.866s | [task-3-link-regression.log](task-3-link-regression.log) |
| Target RED | `/Users/matthew.mcgeary/.copilot/session-state/f45e25ad-38b0-48f9-b9fb-343a546b5c95/files/pio-venv/bin/pio run -d TEENSY_BODY_CONTROLLER -e teensy41` | 1, `HardwareSerial` base lacks pin methods | [task-3-teensy-build.log](task-3-teensy-build.log) |
| Target API fixture RED | `PYTHONPATH=tests python3 -m unittest test_body_radio.BodyRadioTests.test_hardware_startup_rx_only_bounded_pump_and_write_clipping -v` | 1, native fixture now reproduces same target API error | [task-3-uart-type-red.log](task-3-uart-type-red.log) |
| Target GREEN | `/Users/matthew.mcgeary/.copilot/session-state/f45e25ad-38b0-48f9-b9fb-343a546b5c95/files/pio-venv/bin/pio run -d TEENSY_BODY_CONTROLLER -e teensy41` | 0, success in 5.99s | [task-3-teensy-build-green.log](task-3-teensy-build-green.log) |
| Final combined verification | `PYTHONPATH=tests python3 -m unittest test_body_radio test_body_link -v` | 0, **63 passed in 41.845s** | [task-3-final-tests.log](task-3-final-tests.log) |
| Final target verification | `/Users/matthew.mcgeary/.copilot/session-state/f45e25ad-38b0-48f9-b9fb-343a546b5c95/files/pio-venv/bin/pio run -d TEENSY_BODY_CONTROLLER -e teensy41` | 0, **success in 0.75s** | [task-3-final-build.log](task-3-final-build.log) |

Representative exact RED outputs:

```text
clang++: error: no such file or directory: '.../body/IbusInput.cpp'
clang++: error: no such file or directory: '.../body/IbusTelemetry.cpp'
Ran 9 tests in 0.501s
FAILED (failures=9)

Assertion failed: (p.tx==Bytes({4,0x81,0x7a,0xff,4,0x82,0x79,0xff})), function main, file test.cpp, line 55.
Ran 1 test in 1.039s
FAILED (failures=1)

Assertion failed: (u.counters().valid_polls==2 && u.counters().busy_polls==1), function main, file test.cpp, line 65.
Ran 1 test in 0.674s
FAILED (failures=1)

src/body/HardwareAdapters.h:31:17: error: 'class HardwareSerial' has no member named 'setRX'
src/body/HardwareAdapters.h:52:17: error: 'class HardwareSerial' has no member named 'setTX'
========================== [FAILED] Took 2.33 seconds ==========================
```

Final radio test output:

```text
test_actual_main_starts_radio_only_without_waiting_or_actuators ... ok
test_all_or_none_capacity_deadline_and_partial_writes_no_mix ... ok
test_bad_measurements_never_overflow_and_validity_independent ... ok
test_checksum_headers_and_flags_use_only_ch6_and_ch9 ... ok
test_checksum_unknown_poll_echo_and_response_echo ... ok
test_echo_shared_prefix_does_not_eat_real_poll_and_recovery_keeps_suffix ... ok
test_golden_sensors_and_scheduler_boundaries ... ok
test_hardware_startup_rx_only_bounded_pump_and_write_clipping ... ok
test_invalid_all_fourteen_fields_preserve_snapshot_and_time ... ok
test_overlap_partial_expiry_and_rollover ... ok
test_telemetry_overlap_partial_expiry_and_loopback_each_partial_write ... ok
Ran 11 tests in 9.417s
OK
```

Final combined test and target output:

```text
Ran 63 tests in 41.845s
OK

teensy_size: Memory Usage on Teensy 4.1:
teensy_size:   FLASH: code:52512, data:8460, headers:8656   free for files:8056836
teensy_size:    RAM1: variables:16608, code:49960, padding:15576   free for local variables:442144
teensy_size:    RAM2: variables:12416  free for malloc/new:511872
========================= [SUCCESS] Took 0.75 seconds =========================
```

`git diff --check` also completed successfully before staging. The only build
environment warning was PlatformIO's existing urllib3/LibreSSL warning, not a
firmware compiler error. Actual-main native compilation also surfaced the
existing unused `used` variable warning in shared `Endpoint.cpp`; it was not
changed.

## Test coverage and explicit limits

The tests compile/link **actual production .cpp files**, not parallel parsers.
They cover every raw channel's invalid values (0,899,2101,65535), including
unused CH14; unchanged previous channels/time/count; accepted raw endpoints;
checksum/header rejection; switch flags/mapping; exact age and partial expiry
boundaries; overlapping headers; uint32 rollover; all six literal telemetry
response vectors; exact 99/100/999/1000/1001us scheduling; false/invalidated
measurements and extreme signed inputs; capacity below full response size;
queued timeout; partial writes and stalled suffix ownership; malformed
checksums; unsupported commands/addresses; duplicate receiver polls; local
discovery/type echo; non-echo polls sharing response prefixes; unsolicited
responses; bounded UART pumps; clipping/zero-capacity writes; and actual-main
radio-only startup with unavailable USB.

Remaining physical/integration concerns (not reasons to instantiate actuators):

1. No hardware upload or handheld/shifter test was performed. UART enqueue
   timing counters are not electrical timing-margin measurements.
2. Discovery reply bytes are identical to discovery poll bytes. Within the
   short local echo guard an identical packet cannot be distinguished from a
   local loopback without UART-origin metadata. Different polls sharing a
   prefix are correctly retained; the next identical poll after expiry works.
3. A generic transport that accepts a prefix and then stalls cannot satisfy
   both an absolute 1ms completion guarantee and intact framing. The fallback
   counts the miss and preserves only that suffix, rejecting new polls until
   completion. Production single-writer HardwareSerial capacity clipping
   prevents the normal cause of this condition. This fallback is tested rather
   than claiming a timing guarantee under arbitrary transport failure.
4. Task 4 must supply source freshness/aggregation and invalidate each stale
   sensor. Until then discovery/type are available but main's measurements
   stay invalid; no fake zeros are published as valid data.

## Commit

Commit **`083af28`** (parent **`8272d89`**), nine code/test files only:
`feat: add Teensy iBUS input and sensor telemetry`

Includes `Co-authored-by: Copilot <223556219+Copilot@users.noreply.github.com>`.
No physical documentation or local report/log artifacts are included.

Post-commit status contains only the unrelated physical-documentation changes
present at task start. No Task 3 production/test changes remain uncommitted.

## Task 3 round 1 — recovered receiver-header age

The recovered overlapping 0x20 0x40 header previously inherited the original
candidate's `started_ms_`. In the reported trace, that made a valid header
arriving at 2ms appear 5ms old when its final seven bytes arrived at 5ms.
`IbusInput` now keeps a fixed 32-entry arrival-time array parallel to its byte
buffer. Candidate suffix recovery and expiry shift both arrays together;
expiry removes stale candidate bytes while retaining a younger overlapping
header with its original timestamp. Later bytes never renew that timestamp.
Unsigned subtraction is retained for millis rollover.

| Phase | Exact validation command | Exit/result | Full output artifact |
| --- | --- | --- | --- |
| RED | `PYTHONPATH=tests python3 -m unittest test_body_radio.BodyRadioTests.test_recovered_overlap_keeps_header_arrival_time -v` | 1, failed at expected sample assertion for recovered frame | [task-3-overlap-timestamp-red.log](task-3-overlap-timestamp-red.log) |
| GREEN | `PYTHONPATH=tests python3 -m unittest test_body_radio.BodyRadioTests.test_recovered_overlap_keeps_header_arrival_time -v` | 0, 1 passed | [task-3-overlap-timestamp-green.log](task-3-overlap-timestamp-green.log) |
| Radio regression suite | `PYTHONPATH=tests python3 -m unittest test_body_radio -v` | 0, 12 passed | [task-3-round1-radio.log](task-3-round1-radio.log) |
| Teensy 4.1 target build | `/Users/matthew.mcgeary/.copilot/session-state/f45e25ad-38b0-48f9-b9fb-343a546b5c95/files/pio-venv/bin/pio run -d TEENSY_BODY_CONTROLLER -e teensy41` | 0, success in 0.81s | [task-3-round1-teensy-build.log](task-3-round1-teensy-build.log) |

The regression includes the exact 0/2/4/5ms trace, an overlapping candidate
expiring across uint32 rollover while retaining its younger valid header, and
a later-byte case proving a retained candidate still expires based on its
header's original arrival rather than being kept fresh. Task 3 round 1 changed
only `IbusInput.{h,cpp}`, `tests/test_body_radio.py`, and this local report.

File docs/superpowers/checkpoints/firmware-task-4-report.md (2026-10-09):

# Task 4 report — independent VESC UART links

## Status and scope

**Software implementation verified and committed. Hardware acceptance UNPERFORMED; motion remains disabled.** Only Task 4 was implemented. No nested agents, firmware compatibility whitelist, actual firmware defaults, EEPROM adapter, drive owner/arming logic, or other task was added.

Commit: `220e8cb0283e859518ebf1d510a05bc4f1376b04`

Message: `feat: add independent VESC UART drivers`

Trailer: `Co-authored-by: Copilot <223556219+Copilot@users.noreply.github.com>`

Seven committed code/test files:

- `TEENSY_BODY_CONTROLLER/src/body/VescLink.h`
- `TEENSY_BODY_CONTROLLER/src/body/VescLink.cpp`
- `TEENSY_BODY_CONTROLLER/src/body/HardwareAdapters.h`
- `TEENSY_BODY_CONTROLLER/src/main.cpp`
- `tests/test_body_vesc.py`
- `tests/test_body_radio.py`
- `tests/radio_fakes/Arduino.h`

The pre-existing untracked `BODY_CONTROLLER_COMMISSIONING.md` was updated **in the workspace only**. Its new “Task 4 stationary USB firmware / raw-values capture” subsection covers dome removal/service access, elevated/inhibited capture, raw chunk reconstruction, VESC Tool comparison, explicit acceptance, and no rotating tether. There is no tracked baseline against which to isolate that subsection; the whole unrelated physical-documentation file was deliberately NOT staged in the code commit. Include/review it in a future dedicated physical-documentation commit. Other prior-phase documentation/workbook/visualizer modifications remain untouched and uncommitted. This report and TDD/build logs remain session/task workspace artifacts.

## Evidence / TDD chronology

1. Read the Task 4 brief, shared `BytePort.h`, current ConfigStore implementation/API, Task 2 report, current adapters/radio tests, and design sections 6/9 before implementation.
2. Added the requested concrete brake encoder assertion **before creating driver source**: count 10, short marker 2, payload length 5, command 7, positive big-endian `00 00 05 DC`, terminator 3. Added independently packed/CRC-generated synthetic fixtures and initial behavior tests.
3. RED: `python3 -m unittest discover -s tests -p test_body_vesc.py` → **9 failures**, `task-4-red.log`. Initial portable tests failed because `VescLink.cpp` did not exist; target-integration assertion failed because main had no VESC UARTs. This initial red is a missing-production-module compilation failure, not a runtime encoder assertion failure; it is not misrepresented as the latter.
4. Initial implementation exposed a test-harness dependency omission: ConfigStore needs shared `src/Codec.cpp` for its persistence CRC. Added that existing production source to the host build, not new tooling.
5. Additional feature/regression RED runs before corresponding fixes:
   - `task-4-main-capture-red.log`: filtered one-packet capture overload missing and actual main/Serial1/2 pin assertions not yet implemented.
   - `task-4-sensors-red.log`: missing paired sensor aggregation function.
   - `task-4-late-reply-red.log`: query expiry after RX let a stalled reply renew the old sample; moved expiry before RX.
   - `task-4-paired-red.log`: control priority when an unstarted query is blocked, plus missing paired aggregation. Unstarted queries now yield to live commands; a partially written query still finishes without interleaving.
   - `task-4-overlap-red.log`: a damaged CRC packet containing a plausible nested header masked a complete good suffix. Recovery now finds complete CRC/terminator-valid suffixes only after a known-invalid/expired candidate and preserves original header timestamps.
   - `task-4-repeat-demand-red.log`: repeated identical demand corrupted an in-flight partial command. Identical renewals now preserve that frame.
   - `task-4-brake-priority-red.log`: later duty cancelled a pending brake. Brake now has priority through completion; intervening duty is dropped, not delayed/replayed.
   - `task-4-unsent-query-red.log`: an unsolicited values packet freshened a query that had not reached the UART. Values cannot renew the cache until its query is completely written.
6. Final GREEN, after all fixes:

   ```text
   cd tests && python3 -m unittest test_body_vesc test_body_radio test_body_link
   Ran 79 tests in 60.613s
   OK
   ```

   `task-4-final-tests.log` contains the complete output. These cover production C++ modules against injected transports, not Python decoder reimplementations.

7. Final Teensy target build:

   ```text
   /Users/matthew.mcgeary/.copilot/session-state/f45e25ad-38b0-48f9-b9fb-343a546b5c95/files/pio-venv/bin/pio \
       run -d TEENSY_BODY_CONTROLLER -e teensy41
   [SUCCESS] Took 1.03 seconds
   FLASH: code 56160, data 8460, headers 9104
   RAM1: variables 20800, code 53608, padding 11928
   RAM2: variables 12416
   ```

   `task-4-final-build.log` shows both `src/body/VescLink.cpp.o` and `src/main.cpp.o` being compiled and linked into the target. No new dependencies installed.

8. `git diff --check -- TEENSY_BODY_CONTROLLER tests` and `git diff --cached --check` passed. Staged file list was reviewed before committing; no commissioning/physical documentation was staged.

## Public API and readiness contract

The current shared transport remains **`r2link::BytePort`**, included as `"BytePort.h"`:

- `read() -> int`, `-1` when empty.
- `writable() const -> size_t`.
- `write(const uint8_t*, size_t) -> size_t`; partial writes are normal and never waited on.

Portable driver APIs in `body/VescLink.h`:

- `VescProfile()` creates unknown/unaccepted layout and zero fields.
- `VescProfile::fromSaved(const CommissioningProfile&, uint8_t wheel)` injects the existing saved profile and acceptance bits; invalid wheel/profile returns an unknown unaccepted profile. Its acceptance/version/layout members are private; there is no public “infer approval from packet length” constructor.
- `VescCodec::encodeDuty(int16_t permille, uint8_t*, size_t) -> size_t`: native command **5**, signed big-endian `permille * 100`, valid protocol range -1000..1000; zero/error length on invalid arguments/capacity.
- `VescCodec::encodeBrake(uint32_t current_mA, uint8_t*, size_t) -> size_t`: native command **7**, positive signed-32-representable magnitude in mA; rejects zero/overflow/capacity errors.
- `VescCodec::decodeValues(const uint8_t*, size_t, const VescProfile&, VescSample&) -> bool`: command-inclusive payload only, output unchanged on rejection; accepted named layout required. Observed firmware/freshness belongs to `VescLink`, not this payload decoder.
- `VescLink(r2link::BytePort&, uint8_t wheel)`, `tick(uint32_t now_ms)`, `setDuty(int16_t)`, `setBrake(uint32_t)`, `sample(uint32_t) -> VescSample`, `setProfile(const VescProfile&)`.
- `requestCapture(uint8_t command = 255)` and `takeCapture(VescCapture&) -> bool`: next one validated full raw wire frame, optionally restricted to firmware command 0 or values command 4; 255 means any native packet. Diagnostic capture works without an accepted profile. Re-arming replaces an unread capture.
- `counters()` reports frames, CRC/terminator errors, absolute frame expiries, oversized/zero-length frames, unsupported packets/profiles, invalid values, query timeouts, partial writes, aborted commands, and inhibited commands.
- `vescMeasurements(const VescSample& left, const VescSample& right) -> SensorSnapshot`: call with both `sample(now)` records. Healthy fresh approved paired records supply lower pack voltage and hotter MOSFET temperature; faults/stale/invalid sources invalidate handheld measurement flags. Voltage and temperature field masks remain separate.

`VescSample` matches the VESC_STATUS types:

- `wheel`, `fw_major`, `fw_minor`, `fault`: u8.
- `valid_fields`, saturated `source_age_ms`, `pack_cV`: u16.
- `motor_mA`, `input_mA`, `erpm`: i32.
- `mosfet_dC`, `motor_dC`, `duty_permille`: i16.
- `sample_ms`: u32 local receive timestamp.
- `valid`, `profile_match`, `stale`, `unsupported`, `motor_temperature_valid`: separate bools.

Freshness is valid through **500ms**, stale thereafter; absent data has age 65535 and is invalid. `valid` requires voltage/fault/eRPM (`0x49`) plus matched accepted firmware/layout and freshness; **a controller fault remains a separate raw `fault` field**, not conflated with stale/unsupported. `valid_fields = 0xDF` for a successfully decoded legacy packet: every defined field except unused motor temperature. Faulted data remains a fresh valid measurement record, but cannot permit duty and cannot feed healthy paired handheld measurements.

Layout **`body::kLayoutLegacyGetValues = 1`** is the existing ConfigStore enum, not a newly invented firmware list. Layout **0 / kLayoutUnknown** never becomes ready. `fromSaved` first uses the existing `validateProfile`, which checks field-presence/range/acceptance prerequisites. Telemetry profile match requires the per-wheel **`kAcceptVescConfig + wheel`** bit and exactly equal observed firmware major/minor. Actuator transmission additionally requires **`kAcceptTimeoutBrake`, `kAcceptDirection`, and `kAcceptReversal` + wheel**. These flags must come from the existing external commissioning evidence/save workflow, not decoding or building. The driver does not constitute Task 5's paired arming/radio/lock/slew/reversal owner.

Every `setProfile` invocation resets firmware observation, cached sample, and demand; an observed firmware change also resets the sample/demand. Outstanding unsafe command suffixes are invalidated. Fresh matching firmware and a new validated values query/reply are needed afterward.

## Decoder offset cross-check and provenance

Local prior-art: `ASTROPIXELS_PLUS_UNIFIED/ASTROPIXELS_PLUS_UNIFIED.ino`, `parseVescValuesPayload`. Its existing minimum payload length 54, MOSFET/current/eRPM/voltage/fault offsets match the legacy prefix. Unlike that older parser, this driver never left-shifts signed bytes or treats disconnected motor TEMP as valid.

Public reference inspected on 2026-10-09:

`https://github.com/vedderb/bldc/blob/e22727a69cbcb8de9b02e01cca2bb6d6807292c5/comm/commands.c`

Specifically `COMM_GET_VALUES` serialization (full nonselective mask). Upstream SHA was obtained from GitHub's master commit API at inspection time. This public protocol/source cross-check establishes the **shape**, not installed-controller compatibility. No upstream implementation was copied into production.

Offsets below count from the payload's command byte, not the short/long frame header:

| Payload bytes | Wire field/type | Driver representation |
| --- | --- | --- |
| 0 | COMM_GET_VALUES = 4, u8 | command check |
| 1..2 | FET temperature, signed BE i16, ×10 °C | i16 dC, unchanged |
| 3..4 | motor temperature, signed BE i16 | ignored; motor TEMP not wired, validity false |
| 5..8 | average motor current, signed BE i32, ×100 A | i32 mA = wire ×10 |
| 9..12 | average input current, signed BE i32, ×100 A | i32 mA = wire ×10 |
| 13..16 | average d-axis current, i32 | ignored; occupies four bytes |
| 17..20 | average q-axis current, i32 | ignored; occupies four bytes |
| 21..22 | duty, signed BE i16, ×1000 | i16 permille, unchanged |
| 23..26 | electrical RPM, signed BE i32 | i32 eRPM, unchanged |
| 27..28 | input voltage, signed BE i16, ×10 V | nonnegative u16 cV = wire ×10 |
| 29..44 | four amp-hour/watt-hour fields, i32 each | ignored; occupies 16 bytes |
| 45..48 | signed tachometer, i32 | ignored |
| 49..52 | absolute tachometer, i32 | ignored |
| 53 | raw fault code, u8 | u8 fault; any nonzero value inhibits duty |
| 54 onward | firmware-dependent extension | ignored only after explicit exact-version/layout acceptance |

Every decoded field uses a bounds-checked byte reader and unsigned shift/assembly, with explicit mathematical signed conversion. Every i32 current multiplication is checked for i32 overflow; voltage is checked for nonnegativity/u16 conversion overflow, and duty for the protocol's ±1000 range. These are **representation/protocol checks, not guessed physical maximum currents**. Failed decoding leaves the entire old sample/timestamp unchanged.

Test fixture provenance: `tests/test_body_vesc.py` constructs payloads and frames in test code; its independent reference CRC uses polynomial 0x1021, initial 0. These are **synthetic**, not installed-device captures. Firmware **42.19** is deliberately arbitrary synthetic test metadata, never a compatibility whitelist entry or shipping accepted profile. The synthetic values record has MOSFET -125dC, motor current -123450mA, input current +2340mA, duty -350permille, eRPM -98765, input voltage 1280cV, and fault 0; motor temperature bytes are filled with 999 to verify they do not grant validity. Additional synthetic tests cover faults, truncation, malformed fields, current overflow, and long 256-byte payloads.

## Framing, scheduling and command safety

- Native query IDs: **FW_VERSION 0**, **GET_VALUES 4**. Only **SET_DUTY 5** and **SET_CURRENT_BRAKE 7** actuator encoders exist; no CAN forwarding/command 34 or controller-ID wrapper is emitted.
- Short marker 2/one-byte length and long marker 3/two-byte big-endian length, CRC-16 and terminator 3 are validated. Maximum payload 256 bytes; maximum captured wire frame 263 bytes. Zero/oversized lengths and unknown native commands have diagnostics.
- Absolute frame expiry **50ms from the candidate header**, not the last byte. Overlap recovery preserves individual header arrival times; corrupted/trickled packets cannot extend their expiry or freshen a sample. Complete valid suffix recovery is enabled only after known corruption/expiry, not inside an intact live frame.
- One independent parser/capture/cache/query state per wheel. Each tick consumes at most **64 RX bytes** and makes at most **one <=16-byte TX write**; no flush, wait-for-data, delay, or hardware wait loop.
- Firmware first, then query cadence **100ms**, at most one outstanding query. Firmware rechecked at least once per 1000ms of successful observation during ongoing polls. Completed-query response timeout **150ms**, checked before queued RX. Invalid/unsupported/late/unsolicited values do not renew the old sample. A values reply cannot renew an uncompleted TX request.
- Commands take precedence over new queries; a wholly unstarted query yields, but a partial query must finish atomically before a command. Never mix frame prefixes/suffixes.
- Latest nonzero duty demand coalesces, unrenewed duty expires after **20ms** using the last loop tick timestamp; callers must tick regularly and renew live intent. A command is gated again at TX time by accepted matching profile, freshness/required fields, and fault status.
- Brake wins over intervening duty until brake completion; intervening duty requests are dropped rather than replayed later. Brake magnitude must equal the saved accepted profile's positive brake current; zero duty requests that approved brake, not a guessed current.
- A brake supersedes an old queued/partial nonzero command. An unstarted old command is discarded. A committed prefix cannot be unsent, so an unsent CRC byte (or final terminator at the last partial offset) is poisoned; the old frame can never complete as a valid nonzero command after that brake request. The bounded invalid suffix finishes before the valid brake starts. Tests exercise **all partial offsets 1..9**. Already fully transmitted duty cannot be retracted.
- Identical demand renewals preserve a partial frame, avoiding starvation/corruption when the owner repeats live demand during a partial write.
- On stale data, unsupported firmware/profile, or loss of acceptance, no guessed actuator command is sent. External VESC timeout/braking configuration and its hardware acceptance remain essential.

Native VESC query replies have no sequence/session ID. The driver rejects unsolicited, expired and pre-transmission values, but an old reply arriving during a later completely transmitted same-command query is indistinguishable on this protocol. Hardware timing/configuration acceptance and the higher-level drive owner remain necessary; do not claim cryptographic/session-correlated telemetry.

## Real target integration and capture procedure

`body::VescPort` wraps the existing nonblocking adapter:

- **Left Serial1**: RX **0**, TX **1**, 115200 8N1.
- **Right Serial2**: RX **7**, TX **8**, 115200 8N1.

Main instantiates both actual adapters and both portable links, configures them in setup, and ticks them in the real loop. It calls paired sensor aggregation before servicing sensor replies. There is no ESP32 pin substitution and no main `setDuty`/`setBrake` call. Profiles remain default zero/unaccepted; startup only sends firmware/value requests. Existing radio UARTs and disabled NullPort body/dome bootstrap remain unchanged in role.

USB capture commands are one character: **L/R** capture that wheel's next FW_VERSION reply; **l/r** capture its next GET_VALUES reply. Reporting uses bounded `VESC_RAW wheel=… offset=… length=… HEX…` lines, at most 16 raw bytes per loop and only when USB has room. No automatic raw stream, actuator CLI, wait-for-host or flush. Capture is raw wire data, including header/length/CRC/terminator, and remains accessible when the profile is unsupported/unaccepted. Wait for the complete report before another request. Missing hardware may produce no report; it is not a pass.

The workspace commissioning subsection requires dome removal for USB access, elevated wheels, inhibited feet/dome, full raw fixture provenance, matching VESC Tool comparison, separate per-wheel acceptance, and removal of every external tether before rotation/reassembly. Stationary near-zero-current data alone is not proof of signed-current scaling; unresolved checks remain unperformed.

## Remaining hardware and integration gates

| Required observation | Left | Right |
| --- | --- | --- |
| Installed firmware major/minor and controller identity | **UNPERFORMED** | **UNPERFORMED** |
| Real FW_VERSION / GET_VALUES full byte fixture capture | **UNPERFORMED** | **UNPERFORMED** |
| Firmware-specific legacy-layout verification | **UNPERFORMED** | **UNPERFORMED** |
| Decoded fields compared against VESC Tool, including current sign/scaling | **UNPERFORMED** | **UNPERFORMED** |
| Operator-confirmed saved firmware/layout/current-profile acceptance | **UNPERFORMED** | **UNPERFORMED** |
| Applied VESC Tool current/voltage/150ms timeout/brake settings | **UNPERFORMED** | **UNPERFORMED** |
| Timeout braking / direction / reversal external acceptance | **UNPERFORMED** | **UNPERFORMED** |
| Electrical UART operation, sustained RC/sensor concurrency and installed timing | **UNPERFORMED** | **UNPERFORMED** |

No hardware was available. No raw hardware fixture, installed firmware version or compatibility approval is fabricated. Build/test success does not enable either wheel or set acceptance. Future integration must load only the genuinely saved/accepted profile, preserve paired-drive inhibition and owner safety rules, and perform the remaining physical checks. Physical USB buffer behavior and VESC rejection/recovery of deliberately invalidated partial frames still require installed verification; the 150ms external timeout remains the fallback, not a software assertion of measured stopping distance.

## Fix round 1 (review of 220e8cb)

Scope: only `VescLink.h/.cpp` and `tests/test_body_vesc.py`. No other drivers, docs, tasks or nested agents.

**Important 1 — stale telemetry suppressed safety brake.** Brake (start and in-flight) previously required a fresh valid sample. Now `brakePermitted()` = actuator-accepted profile (`kAcceptVescConfig/TimeoutBrake/Direction/Reversal` + wheel) **and** observed firmware exactly matching the profile **and** magnitude equal to the saved `brake_ma`. Stale/missing RX no longer blocks brake; duty keeps the fresh/valid/unfaulted/20ms gate at stage and every TX tick. Profile change to unaccepted (`setProfile`) or observed firmware change poisons any partial brake and emits nothing; never-observed firmware emits nothing. A staged/partial old duty is still poisoned (CRC/terminator) then replaced by the brake, including when the duty went stale mid-frame (offsets 1..9 tested).

**Important 2 — per-tick control starved polling.** New TX timing contract per `tick()`:
- Byte budget `kTxBudget = 32` per tick (~2.8ms of line time at 115200 8N1; a 10-byte command or 6-byte query is <1ms). Finish any partial frame, then start at most **two** new frames. After the first write of a tick, a further frame starts only if it fits whole in `min(writable(), remaining budget)`; no needless partial frames.
- Selection order: **brake > waiting query > duty > due query**. A due query goes out in the same tick right after control when room allows. If control took the room, the query is marked waiting and goes ahead of the next duty renewal (delay ≤6 bytes); it never goes ahead of brake.
- Brake displaces an unstarted query; duty no longer cancels an unstarted query. A partially written query still completes first (≤6 bytes) — never interleaved.
- Query reply timeout (150ms) is now evaluated whenever the query itself is not in TX, even while a command occupies TX.
- Guarantee: with regular ticks, a poll opportunity arises at least every 100ms + ≤2 loop periods regardless of duty renewal rate; poll/firmware cadence otherwise unchanged (100ms, FW recheck ≥1000ms, one outstanding).

Contract change reflected in one existing assertion: a brake issued when a query is due is now followed by that query in the same tick (`test_control_priority…`).

**Tests added** (production C++ against fakes; reference CRC/frame parser in test code):
- `test_live_duplex_continuous_duty_never_starves_polls`: duplex fake drains TX FIFO at 11.52 bytes/ms into a reference VESC that replies FW/GET_VALUES after 3ms. For loop/renewal (1ms/every tick, 1/20, 5/every, 7/every, 5/20) over 2.1s of continuous duty: sample valid and age ≤250ms every tick, poll gaps ≤100+2·loop+3ms, duty gaps ≤ renewal+loop+3ms through the end, zero query timeouts and zero aborted commands.
- `test_live_duplex_small_fifo_brake_urgent_and_due_query_both_progress`: 12-byte FIFO, duty every 1ms tick, five urgent brakes on the wire within 4ms of request, polls gap ≤106ms; same-tick brake+due query order; partial capacity brake first then query next tick; fairness with 10-byte room per tick.
- `test_stale_rx_brake_still_sent_but_duty_blocked`: stale sample → duty blocked, `setBrake`/`setDuty(0)` brake sent; brake with no values ever received; stale partial duty poisoned then brake; stale partial brake completes intact.
- `test_brake_requires_accepted_profile_and_matching_firmware`: FW change, unaccepted profile mid-brake, never-observed FW, missing reversal acceptance → no brake frame.

**RED**: `cd tests && python3 -m unittest -v test_body_vesc` → `Ran 19 tests … FAILED (failures=5)` (continuous duty loops 1/5/7ms: sample stale; small-FIFO/fairness; stale brake `count(p.tx,7)==1`). The brake-gating test passed pre-fix (existing gates already held) and is kept as a regression. Log: `task-4-fix1-red.log`.

**GREEN**: `cd tests && python3 -m unittest -v test_body_vesc test_body_radio test_body_link` → `Ran 83 tests in 66.124s OK`. Log: `task-4-fix1-green.log`.

**Build**: `…/files/pio-venv/bin/pio run -d TEENSY_BODY_CONTROLLER -e teensy41` → `[SUCCESS]`, VescLink.cpp recompiled; FLASH code 56608, RAM1 variables 20800. Log: `task-4-fix1-build.log`. `git diff --check` clean.

Hardware acceptance remains UNPERFORMED; motion remains disabled (main still never calls `setDuty`/`setBrake`).

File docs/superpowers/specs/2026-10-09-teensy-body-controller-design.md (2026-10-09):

# Teensy Body Controller Design

**Status:** Hardware/fuses and operator behaviour approved in conversation. Revised firmware design and implementation plan incorporate those decisions; firmware is unchanged. The physical documents completed earlier still require the second Hall/GPIO18 and radio-policy revisions listed in firmware Task10. Nothing has been wired.

**Execution order:** Review the first-build design, update physical documentation, then build firmware. Assemble and commission the hardware after both firmware builds are ready.

**First-build scope:** There is no installed harness to preserve or disconnect. Prior wiring assignments, fuse values, connector choices and assembly methods are design inputs, not compatibility requirements. Change them when the result is safer, simpler or easier to service. Keep the purchased Teensy 4.1 and Treedix carrier; identify any additional parts and changes to explicit user selections before incorporating them.

## 1. Decisions

### Approved dome-position revision

Use **two KY-003 / 3144E Hall modules and one magnet**, not an encoder. Mount both modules on the rotating dome, 180 degrees apart, and the single magnet on the stationary body structure at their sensing radius. Front detection identifies dome-forward; rear detection identifies dome-backward. Align both sensing faces so the same magnet pole reliably triggers each module, with clearance throughout rotation.

Both modules: `-` to dome ground; centre `+` to D-LOGIC fused 5V. Front `S` -> dome shifter HV2/B2 -> LV2/A2 -> ESP32 GPIO19. Rear `S` -> HV3/B3 -> LV3/A3 -> GPIO18. Shifter HV=5V, LV=ESP32 3.3V, ground common. GPIO18 is now assigned, not spare; only shifter channels 1 and 4 remain unused.

These provide two discrete reference positions, not continuous angle feedback. Estimate intermediate movement from calibrated direction/speed/time and re-reference when a sensor activates. Do not report estimated angles as measured positions.

ESP32 selects autonomous idle/event dome motion. Teensy owns the actuator, immediate manual override and driving alignment priority. CH9/SwD enables automatic dome motion independently of CH6 foot enable. Holos have no radio controls. The operator behaviour below incorporates the subsequent approved decisions. Firmware implementation remains a separate phase.

The body controller is a **Teensy 4.1 in the ordered Treedix socketed screw-terminal carrier**. Do not replace this with an Arduino, another ESP32, or a perfboard carrier.

The FlySky FS-iA6B receiver moves into the body. Teensy controls both foot motors, the dome rotation servo, and the DFPlayer Mini. AstroPixels ESP32 controls dome lighting, the six holo servos, Wi-Fi, the dashboard, and behavioural choreography.

Each VESC connects directly to a separate Teensy UART. Both links carry commands and feedback. Internal CAN forwarding is removed. Set the internal CAN switch OFF and disable multi-controller command forwarding on both controllers.

Two slip-ring contacts carry the body/dome serial link. Two contacts become spares.

The user selected these additional changes during planning:

- **CH6 / SwA is drive enable.** OFF stops and disarms the feet. ON permits drive after throttle and steering remain centered for 500ms. Receiver failsafe sets CH6 OFF.
- **VESC voltage supplies handheld battery telemetry.** FS-CVT01 is not installed in the active wiring. F6 becomes an empty spare. Keep the sensor's BOM entry and mark it unused in this architecture.
- Documentation uses plain, declarative language. State selections, connections, ownership, and measured setup steps. Do not surround documented specifications with hypothetical exceptions.
- **Keep the owned screw-terminal 5V distribution in body and dome.** Use selective inline fuse holders where branch protection is needed; do not add separate 5V fuse boxes.
- **All four 5V fuse ratings are approved:** B-SERVO body dome servo **5A**; B-LOGIC Teensy/receiver/DFPlayer/body shifter **2A**; D-SERVO PCA9685 V+ / six holo servos **5A**; D-LOGIC AstroPixels/Hall/dome shifter **3A**. These are the assembly values, not pending choices.
- **Dome holo-servo fuse is fixed at 5A by user decision.** Connect dome distribution positive through that inline fuse and a 16AWG feed to PCA9685 V+ screw terminal; use a 16AWG unfused ground return. Six MG90S servos use their normal three-pin sockets. PCA9685 logic VCC remains ESP32 3.3V. Do not increase the fuse after a fault; diagnose the fault.
- **Owned inline holders:** Amazon B0FDJYRGB7, indexed as Cooclensportey four-pack, 12AWG leads, standard automotive blade format. Use these for all four branches. The indexed assortment starts at 5A; obtain matching standard ATO/ATC **2A and 3A** separately. Use two included 5A fuses for the servo branches.
- **Use Lonely Binary MOSFET logic converters from kit B0FFMLDYNY in both body and dome.** Allocate one four-channel module to each location. The previous converters are being returned and are not part of this build. Do not substitute TXS0108E or Pololu boards.
- **No oscilloscope or logic analyzer is available or required.** Assembly, commissioning and troubleshooting use a multimeter, USB diagnostics, VESC Tool and the handheld sensor display.

The control policies below are part of this proposed design. Approval of these documents authorizes their implementation; ordering hardware alone does not authorize firmware changes.

## 2. Ownership

| Function | Owner | Other board's role |
| --- | --- | --- |
| Receiver channel decoding and input timeout | Teensy | ESP32 receives channel snapshots and their age |
| Drive enable, tank mixing, drive limits and braking | Teensy | ESP32 receives state; requests foot motion through the defined gated interface |
| Left/right VESC command and telemetry links | Teensy | ESP32 displays both controllers' feedback |
| Handheld telemetry | Teensy | Receiver carries supported sensor readings back to FS-i6X |
| Dome servo pulses and manual override | Teensy | ESP32 requests behavioural rotation |
| Front/rear Hall electrical input | ESP32 | Teensy receives both states and owns seek/position estimation |
| DFPlayer UART, device initialization and playback state | Teensy | ESP32 requests sounds and consumes status/events |
| Sound banks, ambient selection and sound preferences | ESP32 | Teensy executes selected tracks; it does not run a second ambient scheduler |
| Lighting, holo servo choreography and macro selection | ESP32 | Teensy supplies actuator acknowledgements and completion events |
| Wi-Fi, dashboard, preferences and dome OTA | ESP32 | Teensy acknowledges maintenance lock before updates |

There is one actuator owner. ESP32 never writes VESC packets, DFPlayer packets, or dome servo pulses after migration.

## 3. Power and physical pin map

The current design uses the selected battery, cutoff, shared VESC input, converters, motors, amplifier, isolator, speaker and dome mechanism. Their wiring, protection and mounting are reviewed for first assembly rather than copied as an installed system.

The approved 12V fuse schedule is: main 25A; F1 VESC 15A; F2 empty; F3 body buck 7.5A; F4 dome feed 7.5A; F5 amplifier 5A; F6 empty.

Use the owned screw-terminal distribution for each separate 5V rail with B-SERVO 5A, B-LOGIC 2A, D-SERVO 5A and D-LOGIC 3A inline branches. No separate 5V fuse boxes. Locate each fuse at its distribution takeoff, before the smaller branch cable; keep grounds unfused. Split each fused electronics output using insulated terminals separate from the unfused positive bus. Never jumper it back to that bus. Continuity-check the owned dual-row blocks before forming positive/ground groups with correctly sized jumpers. A fuse is wiring fault protection, not an accurate current limiter or a guarantee of semiconductor survival. Stop for hot leads/terminals or jams and diagnose a blown fuse; do not increase these values.

Body 5V powers Teensy VIN, receiver, DFPlayer, dome servo, and the body shifter HV reference. Teensy 3.3V powers only the body shifter LV reference. Do not power the servo, receiver, or DFPlayer from Teensy pins.

Dome 5V powers AstroPixels, PCA9685 V+, both Hall modules, and the dome shifter HV reference. ESP32 3.3V powers PCA9685 VCC and the dome shifter LV reference.

Body and dome 5V positives remain separate. Grounds are common.

### Teensy carrier terminals

Use the terminal labels, not terminal positions counted from a photograph. With all power disconnected, confirm carrier-terminal continuity to its Teensy socket before assembling cables.

| Teensy terminal | Interface | Connect to | Baud / signal |
| --- | --- | --- | --- |
| 1 | Serial1 TX | Left VESC COMM RX | 115200, 8N1, 3.3V |
| 0 | Serial1 RX | Left VESC COMM TX | 115200, 8N1, 3.3V |
| 8 | Serial2 TX | Right VESC COMM RX | 115200, 8N1, 3.3V |
| 7 | Serial2 RX | Right VESC COMM TX | 115200, 8N1, 3.3V |
| 14 | Serial3 TX | 1k ohm resistor, then DFPlayer RX | 9600, 8N1, 3.3V |
| 15 | Serial3 RX | DFPlayer TX | 9600, 8N1, 3.3V |
| 17 | Serial4 TX | Slip ring BODY CH3 | 115200, 8N1, 3.3V |
| 16 | Serial4 RX | Slip ring BODY CH6 | 115200, 8N1, 3.3V |
| 21 | Serial5 RX | Body shifter LV1 | 115200 iBUS channel input |
| 24 | Serial6 single-wire TX/RX | Body shifter LV2 | 115200 iBUS sensor bus |
| 2 | Dome servo pulses | Body shifter LV3 | 50Hz, calibrated 1000-2000us range |
| VIN | Supply | Body regulated 5V | Power input |
| GND | Reference | Body ground distribution | Common ground |
| 3.3V | Reference supply | Body shifter LV | 3.3V reference |

This uses **14 Teensy terminal connections: 11 signal terminals and three supply/reference terminals**. Serial5 TX20 and Serial6 RX25 are unused. Serial7 and Serial8 are spare. USB debug is independent.

DFPlayer BUSY is not wired in version 1. Playback status comes through DFPlayer TX.

### Body MOSFET shifter

Use a Lonely Binary four-channel module. In the tables, LV1-LV4 mean its low-side channel pins (A1-A4); HV1-HV4 mean its matching high-side pins (B1-B4). Follow the supplied PCB labels and confirm channel pairing before wiring. The manufacturer documents 10k ohm pull-ups and 115200-baud UART operation with short jumpers. LV/HV are supply references, not regulator outputs; this module does not generate 3.3V.

| Channel | HV side | LV side |
| --- | --- | --- |
| 1 | Receiver iBUS SERVO signal | Teensy RX21 |
| 2 | Receiver iBUS SENSOR signal | Teensy single-wire pin24 |
| 3 | Dome servo signal | Teensy pin2 |
| 4 | Unconnected | Unconnected |

HV connects to B-LOGIC 2A fused body 5V, LV to Teensy 3.3V, GND to body ground. Leave spare signal terminals insulated.

Serial6 uses Teensy's native half-duplex mode on TX24, with open-drain output. Start it with `Serial6.begin(115200, SERIAL_8N1_HALF_DUPLEX)` and then `Serial6.setTX(24, true)`. Configure open drain after `begin`, because initialization sets the pin pad configuration. RX25 is not connected. The MOSFET shifter supplies the two voltage-domain pull-ups; Teensy drives low or releases the line. Do not join push-pull TX and RX.

Mount the module beside Teensy and the receiver and keep the iBUS connections short. Commission with concurrent channel input and sensor telemetry, checking parser errors, valid-frame counts, sample ages and sensor responses. No waveform measurement or rise-time acceptance gate is required. USB timing counters verify firmware scheduling, not electrical edge shape. Functional communication tests demonstrate operation but do not measure electrical timing margin.

If communication fails, keep motion disabled. Check unpowered continuity and channel pairing, check powered LV/HV rails with a multimeter, inspect common ground and solder joints, test receiver input and sensor telemetry separately with the shortest practical leads, then replace the module with a spare from the selected kit. Repeat the concurrent test before enabling motion. Do not make acquiring an oscilloscope or logic analyzer a recovery step.

### Dome MOSFET shifter

Use a second Lonely Binary four-channel module, with the same low/high channel naming convention.

Front Hall S connects through HV2/LV2 to GPIO19. Rear Hall S connects through HV3/LV3 to GPIO18. Both modules use D-LOGIC fused 5V and common ground. Shifter HV uses D-LOGIC 3A fused dome 5V; LV uses ESP32 3.3V; GND uses dome ground. Channels 1 and 4 are unused.
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

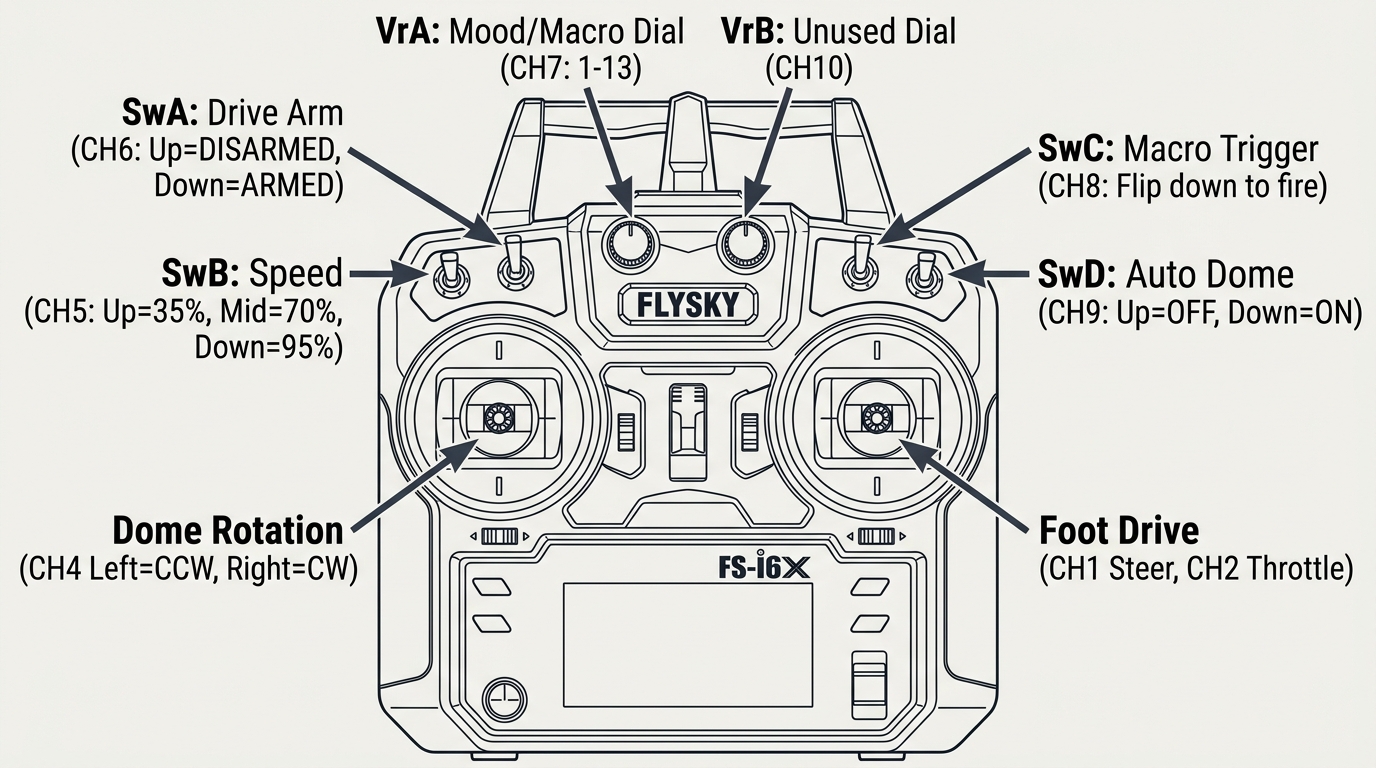
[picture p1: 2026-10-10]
docs/images/flysky_fs_i6x_layout.jpg

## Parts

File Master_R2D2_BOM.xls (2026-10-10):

Item # | Subsystem | Component Name | Status | Qty | Manufacturer / Specification | Notes & Wiring Reference
1 | Chassis & Shell | Base Shell & Body | Ordered / Acquired | 1 | Home Depot Animated R2-D2 Body | Base structural chassis with center post pivot frame
2 | Chassis & Shell | Dome Shell & Pivot | Ordered / Acquired | 1 | Home Depot Animated R2-D2 Dome | Rotating upper dome shell riding on center pivot post
3 | Foot Drive Subsystem | Brushless Hub Motors | Ordered / Acquired | 2 | Razor Tekno Pop 100mm integrated brushless hub motors | 12V known; exact power unconfirmed, roughly80-100W discussed (user estimates100W). Do not derive phase-current limits from wattage. 16mm x11mm Double-D axles.
4 | Foot Drive Subsystem | Dual Motor Controller | Ordered / Acquired | 1 | Flipsky Dual FSESC4.20 100A | Two direct Teensy UARTs: leftTX1/RX0, rightTX8/RX7,115200. CAN switchOFF, forwarding disabled. One shared F1 15A supply; configure each USB separately,150ms timeout and tested braking.
5 | Foot Drive Subsystem | Axle Clamping Mounts | Fabrication (Ready) | 2 pairs | 3D Printed / Plywood 16x11mm Axle Clamps | STL models generated (Razor_Hub_Motor_Axle_Clamp_Top/Bottom.stl)
6 | Foot Drive Subsystem | Hall Sensor Adapters | Ordered / Acquired | 2 | 6-Pin JST-ZH to 5-wire Hall Pigtails | Connects Razor 5-wire Hall sensors to VESC ports
7 | Foot Drive Subsystem | Motor Phase Connectors | Ordered / Acquired | 2 sets | 3.5mm or 4.0mm Gold Bullet Connectors | Connects 3-phase motor wires into VESC outputs
8 | Dome Drive Subsystem | Dome Continuous Servo | Ordered / Acquired | 1 | TIANKONGRC TD-8135MG-360 (35kg 360°) | Body B-SERVO5A fused5V,16AWG trunk; Teensy pin2 via body shifterLV3/HV3. Calibrate neutral unloaded; pulse-sleep disabled until installed signal-loss test passes.
9 | Dome Drive Subsystem | Dome Homing Sensors | Ordered / Acquired | 2 | KY-003 / 3144E Hall Effect Sensors | Dome D-LOGIC fused5V; Front 0° on HV2/LV2 to GPIO19, Rear 180° on HV3/LV3 to GPIO18. ESP32 publishes Hall state to Teensy for homing.
10 | Dome Drive Subsystem | Dome Homing Magnet | Ordered / Acquired | 1 | Neodymium Disc Magnet (~6x2mm or 10x2mm) | Glued to stationary center post base for 0° Home alignment
11 | Dome Drive Subsystem | Center Post Drive Coupler | Ordered / Acquired | 1 | 25T Servo Horn to Center Post Coupler | Couples 35kg servo output directly to dome central pivot post
12 | Dome Brain & Lights | AstroPixels Main Board (Brain) | Ordered / Acquired | 1 | AstroPixels ESP32 30-Pin Module | Dome controller: lights, PCA9685, Hall, choreography, Wi-Fi/OTA. D-LOGIC3A supply. Body link RX16/TX17; target firmware migration complete.
13 | Dome Brain & Lights | Logic Displays (FLD & RLD) | Ordered / Acquired | 3 | AstroPixels WS2812 FLD1/2 & RLD | Front & Rear Logic displays (GPIO 15 & 33)
14 | Dome Brain & Lights | Process State Indicators (PSIs) | Ordered / Acquired | 2 | AstroPixels WS2812 FPSI & RPSI | Front & Rear PSI displays (GPIO 32 & 23)
15 | Dome Brain & Lights | HoloProjector LED Boards | Ordered / Acquired | 3 | AstroPixels WS2812 HP Light Rings | Front, Rear, and Top Holo LED cores (GPIO 25, 26, 27)
16 | Dome Brain & Lights | Holo Micro Servos | Ordered / Acquired | 6 | TowerPro MG90S Metal Gear Servos | 2 servos per HP (Pan & Tilt for 3 Holos) on PCA9685
17 | Dome Brain & Lights | HP 2-Axis Gimbal Brackets | Fabrication (Ready) | 3 | 3D-Printed Custom Pan/Tilt Mounts | Gimbal brackets holding the 3 Holoprojector units
18 | Dome Brain & Lights | I2C PWM Servo Driver | Ordered / Acquired | 1 | PCA9685 16-Channel 12-bit PWM Module | VCC=ESP32 3.3V; SDA21/SCL22/GND from I2C D/C/G, headerV unused. V+ via D-SERVO5A,16AWG feed/return. 0x40,50Hz,channels0-5. Test each servo then all six; stop for heat/jams, do not enlarge fuse.
19 | Dome Brain & Lights | Dome Buffer Capacitor | Optional / Not required | 1 | 1000uF - 2200uF 10V/16V Low-ESR Cap | Diagnostic option for observed supply transients, not a mandatory purchase. Fix wiring/jams before adding capacitance.
20 | Dome Brain & Lights | Dome 5V Distribution Block | Ordered / Acquired | 1 | uxcell 6-Position Dual Row Terminal Block | Owned dome block. Continuity-check isolated pairs; jumper intended5V/GND groups separately. D-SERVO5A and D-LOGIC3A inline branches; separate fused logic fan-out, no bypass jumper. No separate5V fuse box.
21 | Slip Ring Interface | Through-Bore Slip Ring | Ordered / Acquired | 1 | Senring H3086 (30mm ID, 6-Channel 10A) | 17AWG leads,10A/contact. CH1=F4 7.5A battery to dome buck; CH2=GND; CH3=TeensyTX17 to ESP32RX16; CH6=ESP32TX17 to TeensyRX16; CH4/5 insulated spares. Extend power16AWG; no paralleling.
22 | Sound Subsystem (Body) | Sound Engine Module | Ordered / Acquired | 1 | DFPlayer Mini MP3 Player Board | Body B-LOGIC2A fused5V,20AWG. Bidirectional3.3V9600: TeensyTX14 through1k resistor to RX; TX to TeensyRX15. No ring audio line or BUSY wire.
23 | Sound Subsystem (Body) | Sound MicroSD Card | Ordered / Acquired | 1 | 16GB / 32GB MicroSD Card (FAT32) | Preferred Plus firmware: /01/001.mp3 through /01/255.mp3; random chatter banks1-4, explicit reserved macro tracks. See Plus README, not legacy mood-pool layout.
24 | Sound Subsystem (Body) | Audio Series Resistor | Ordered / Acquired | 1 | 1kΩ 1/4W Resistor | TeensyTX14 to DFPlayerRX command line only,3.3V UART. Not a voltage converter. DFPlayerTX directly to TeensyRX15.
25 | Sound Subsystem (Body) | Audio Amplifier | Ordered / Acquired | 1 | HF82 / TPA3110 stereo amp, Amazon.ca B09F2XR9MN; listed8-26V DC,4-10ohm,2x15W; solder-pad connections | Replaces PAM8610. F5 5A battery branch,18AWG supply/return; verify actual pad labels, strain-relieve soldered pigtails. DFPlayer DAC through BESIGN isolator to line input. Speaker negatives are not ground. WiFi volume, default10/30 unless saved setting exists.
26 | Sound Subsystem (Body) | Speaker | Ordered / Acquired | 1 | Nobsound 2.5-inch 8Ω 15W Full-Range | Mounted behind front acoustic vents in body
27 | Sound Subsystem (Body) | Audio Ground Loop Isolator | Ordered / Acquired | 1 | BESIGN3.5mm ground-loop isolator; user-selected Amazon.ca B06XQYN77L, plus2stereo TRS-to-screw-terminal adapters with matching mating connectors | DFPlayer DAC_L/GND to source adapter tip/sleeve; isolator to amplifier adapter tip/sleeve to LINE L/GND. Ring/R unused; no external sleeve bridge. Passive, no power. Not B0505S; not SPK outputs. Speaker across ampL+/L-, neither to ground.
28 | Sound Subsystem (Body) | Audio Volume Potentiometer | Unused / Not required | 1 | 10kΩ Logarithmic Stereo Potentiometer | Wi-Fi volume control; default10/30 unless saved. No separate physical pot.
29 | Power & Safety | 10A 5V Buck Converter | Ordered / Acquired | 1 | Amazon B09T954ZV1: listed10-35V input, fixed5V/10A output,50W, non-isolated | Existing unit in dome, F4 7.5A before ring,16AWG input extensions,12AWG output trunk extensions. Measure fixed output/polarity; verify factory leads. No5.05V adjustment.
30 | Power & Safety | Main Battery Pack | Ordered / Acquired | 1 | Renogy Core 12V 20Ah LiFePO4 (RBT1220LFP-TM) | 20A Continuous / 75A 5s Surge Peak; Grade-A IP65 pack (5.95 lbs)
31 | Power & Safety | Main Battery Charger | Ordered / Acquired | 1 | Purchased ECO-WORTHY nominal10A charger, Amazon.ca B09SYNQNC1; listing LiFePO4 output14.4V9A | Use LiFePO4 mode and supplied SAE ring lead with10A fuse; verify actual label/polarity on arrival. MasterOFF while charging, unplug before drive; no charging below0C. BMS activation is not routine charging.
32 | Power & Safety | Main DC Fuse & Holder | Ordered / Acquired | 1 | 25A fuse, matched holder rated at least32V DC/30A with10AWG pigtails or suitable studs | Battery+ to fuse before cutoff; target at most150mm unfused cable. Protects10AWG harness, does NOT enforce20A battery continuous limit; verify fuse inrush/temperature behavior.
33 | Power & Safety | Tier 1 Master Cutoff Switch | Ordered / Acquired | 1 | Documented DC load-break battery disconnect rated at least30A at16V, covered terminals; higher rating acceptable | After main fuse, before all operating branches; immediately accessible at body hatch/exterior, no reach past wheels. Not anAC-only toggle; charge lead remains live.
34 | Power & Safety | Dome 12V Branch Fuse & Holder | Ordered / Acquired | 1 | 7.5A DC branch fuse, installed as F4 in covered12V fuse block (item44) | Before ringCH1,16AWG extensions/17AWG factory leads. No separate duplicate inline holder if F4 provides source protection. Do not fuse ground; verify factory-lead compatibility.
35 | Power & Safety | Battery Voltage Telemetry Sensor | Unused | 1 | FS-CVT01 sensor; user-selected Amazon.ca B0DQXT337L; no standalone display | Not needed: Teensy replies to receiver SENSOR polls with fresh VESC pack voltage/temperature. F6 empty; no sense cable. Voltage is not charge percentage.
36 | Radio Control | 2.4GHz RC Transmitter | Ordered / Acquired | 1 | FlySky FS-i6X 10-Channel 2.4GHz AFHDS 2A | No transmitter tank mix; Teensy mixes. CH1steer/2throttle/3unused/4dome/5SwB rates/6SwA enable/7VrA/8SwC trigger/9SwD auto dome;10unused. Verify failsafe CH6OFF and centered sticks.
37 | Radio Control | iBus Digital Receiver | Ordered / Acquired | 1 | FlySky FS-iA6B 6/10-Ch iBus Receiver | Body B-LOGIC5V. SERVO via body Lonely Binary HV1/LV1 to TeensyRX21; SENSOR single-wire HV2/LV2 to pin24,115200. No PPM or ring receiver line. TX20/RX25 unused.
38 | Wiring & Hardware | Power Connectors & Wire | Ordered / Acquired | 1 pack | Stranded copper 10/12/16/18/20/22AWG; ring lugs matching studs, insulated crimp splices, and ferrules | Follows wire schedule in POWER_HARNESS_GUIDE.md: 12AWG for motor phases (6x 2m) and VESC power; 22AWG 5-core for motor Halls.
39 | Wiring & Hardware | Keyed Signal Harness Connectors | Ordered / Acquired | 6 pcs | Matching COMM TX/RX/GND pigtails, receiver connectors and labelled detachable UART harnesses | No VESC PPM cables or supply pins. Keep PCA servo factory plugs, no unnecessary thin extensions. Short22AWG signal leads, strain relief and correct terminal ferrules.
40 | Wiring & Hardware | Mounting Standoffs Kit | Ordered / Acquired | 1 kit | M2.5 & M3 Nylon / Brass Standoffs & Screws | Mounts VESC, Buck, Amp, PCA9685, and DFPlayer
41 | Wiring & Hardware | Programming Cable | Ordered / Acquired | 1 set | Data Micro-USB for Teensy4.1/VESC; data cable matching actual ESP32 socket | Teensy VUSB/VIN cut once and carrier isolation checked before externalVIN plus USB. After cut externalVIN required. ESP32 flashed bare, removed from AstroPixels.
42 | Power & Safety | Body 10A 5V Buck Converter | Ordered / Acquired | 1 | Second matching B09T954ZV1-equivalent 10-35V input / fixed 5V 10A converter | F3 7.5A input; B-SERVO5A and B-LOGIC2A output branches. Powers Teensy,receiver,DFPlayer,body shifter and dome servo. Body/dome5V positives separate.
43 | Dome Brain & I/O | Old 3.3V / 5V Logic-Level Shifter | Being returned / Not used | 1 | Old module listing max28,800bps; unsuitable for115200 iBUS | Superseded by selected Lonely Binary kit item50. Do not install old modules.
44 | Power & Safety | Covered 12V Fuse Box with Integrated Negative Bus | Ordered / Acquired | 1 set | 6-way blade fuse block with + and - feed studs and common negative bus | Main25A and cutoff. F1VESC15A,F2empty,F3body7.5A,F4dome7.5A,F5amp5A,F6empty. One12V fuse block; no separate5V fuse boxes.
45 | Power & Safety | Body 5V Screw-Terminal Distribution | Owned | 1 assembly | Owned screw-terminal distribution, separate from dome item20 | Continuity-check terminal pairs, correctly sized jumpers for5V/GND. B-SERVO5A and B-LOGIC2A inline branches; insulated fused electronics fan-out. No output bypass jumper.
46 | Wiring & Hardware | Harness Strain Relief & Labels | Ordered / Acquired | 1 kit | Grommets, abrasion split-loom, screw-mounted clamps, adhesive heatshrink, and wire labels | Protects wiring through shell holes; provides service loops at shoulder pivots and secures connectors.
47 | Power & Safety | Commissioning Measurement Tools | Verify availability | 1 set | Digital multimeter and DC-capable clamp meter or inline wattmeter | Multimeter continuity/voltage plus USB diagnostics, VESC Tool and handheld display. No oscilloscope or logic analyzer. Total20A budget measurement requires rated inline/DC clamp meter; never DMM current mode across battery.
48 | Body Controller | Teensy 4.1 | Ordered | 1 | PJRC Teensy4.1,3.3V I/O; matching male headers if not preinstalled | 14 terminals per BODY_CONTROLLER_WIRING.md; B-LOGIC2A VIN5V. Cut designated underside VUSB/VIN bridge once; verify isolation before ordinaryUSB plus externalVIN.
49 | Body Controller | Treedix Teensy Carrier | Ordered | 1 | Socketed screw-terminal carrier, Amazon.ca B09NXYWYK7 | No perfboard/female sockets needed. Check terminal labels by continuity and no VIN/VUSB re-bridge. Standoffs, short22AWG logic harnesses; servo power bypasses carrier.
50 | Body / Dome I/O | Lonely Binary Logic-Level Converter Kit | Selected / Acquired | 1 kit; use2 four-channel boards | Amazon.ca B0FFMLDYNY,27-piece MOSFET kit,10k pull-ups | Body ch1iBUSinput,ch2single-wiretelemetry,ch3servo; dome ch2 Front Hall, ch3 Rear Hall. LV externally supplied3.3V,HV respective fused5V,common ground. A/B labels alias LV/HV. Short leads; functional115200 checks without scope.
51 | Power & Safety | Four 5V Inline Fuse Holders | Owned | 4 | Amazon.ca B0FDJYRGB7,12AWG leads,standard ATO/ATC blade | Approved B-SERVO=5A,B-LOGIC=2A,D-SERVO=5A,D-LOGIC=3A. Fuse positive at takeoff before smaller branch leads; unfused grounds. Four holders only, no5V fuse boxes.
52 | Power & Safety | 5V Branch Blade Fuses | Ordered / Acquired | 2x5A,1x2A,1x3A plus spares | Standard automotive ATO/ATC matching item51; not mini-blade | Indexed included assortment starts5A. Buy matching2A and3A separately. Do not increase approved ratings after a blown fuse; diagnose fault.

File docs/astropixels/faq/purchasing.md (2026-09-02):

> For the complete documentation index, see [llms.txt](https://r2djp.gitbook.io/astropixels/llms.txt). Markdown versions of documentation pages are available by appending `.md` to page URLs; this page is available as [Markdown](https://r2djp.gitbook.io/astropixels/faq/purchasing.md).

# Purchasing/Shipping

### Can I just send you the money rather than going through your store?

Short answer is no. Using the store lets me keep track of things and makes sure that I don’t miss an order or similar. It also allows me to see the numbers sold and predict when I need to order the next batch. Plus I also then know how much I need to give to charity.

### Before I pay, do you still sell them?

If there is stock in the store, then I have sets more or less ready to ship. At the very least I have enough tested boards ready to be packed up. As per builders club rules, I cannot take pre payments or anything like that. I can only accept money when I have the items in hand.

### Why can I only buy one set at once?

Initially it was because I was only doing smaller runs and wanted to make sure as many people got them as possible. Now I’ve aways got stock I’m very wary of people buying multiple sets with the intention of building droids for sale (this is against club rules). If you want more than one set, feel free to drop me a line. If you don’t communicate with me, I’ll cancel any extra orders.

### Do you ship to ?

I will ship anywhere that the [Royal Mail](https://www.royalmail.com/) allow. However, not all places may be set up on the store so if you can’t select your address, drop me a line and I’ll add it.

### Can I just buy some of the boards

Unfortunately I can't. As I buy them in batches this would leave me with certain boards in stock that would never shift. I just sell the kits as is.

### Can I have a tracking number?

Initially, no orders were sent with tracking numbers. However I am adding the option to more and more locations. Make sure to select the tracked option when ordering.

### I’ve just got a customs charge?

This is down to your own country and I have no control over it. Any package going overseas from the UK will have a customs form on the back stating the price of the contents. On entering your country they may charge you import fees. This is just something to bear in mind when ordering.

### Can you put a lower price on the customs form to save me money?

No, this is illegal.

### Which charity do you donate to and why?

One of the things I love about the community is the charity work done, so when I put the Astropixels up for sale I decided that £10 from each purchase would go to the [Droidbuilders UK](https://droidbuilders.uk/charity) chosen charity. Currently as of September 2024 that is [Alzheimer's Society](https://r2djp.gitbook.io/astropixels/faq/www.alzheimers.org.uk) but we’ve supported many other causes over the years such as [Make a Wish](https://www.make-a-wish.org.uk/), [MNDA](https://www.mndassociation.org/), [Calm](https://www.thecalmzone.net/), and [Meningitis Now](https://www.meningitisnow.org/).

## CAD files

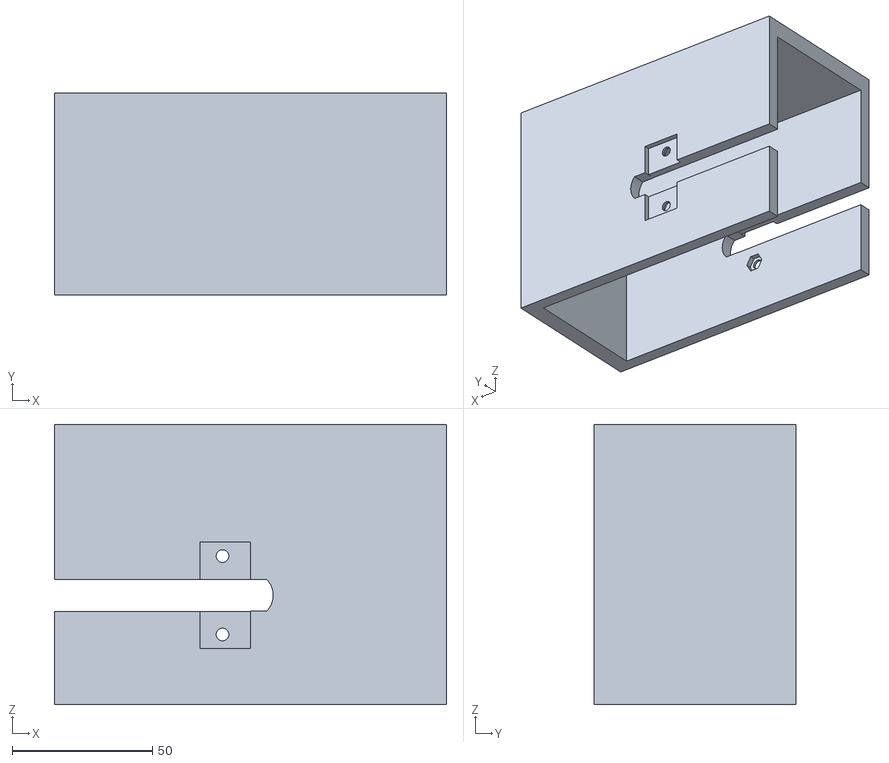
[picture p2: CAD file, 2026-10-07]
mechanical/tekno-pop-motor-mounts-wip/r2d2_clean_motor_mount.stl
140.0 x 72.0 x 100.0

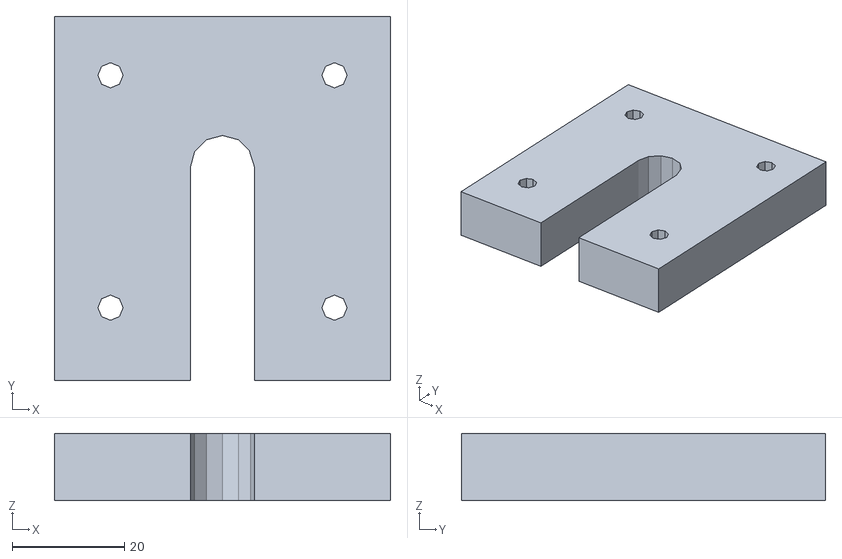
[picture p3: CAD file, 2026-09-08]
Razor_Hub_Motor_Slotted_Mount.stl
60.0 x 65.0 x 12.0

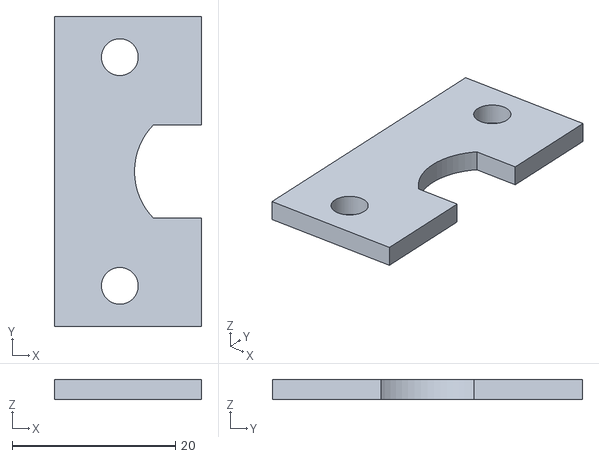
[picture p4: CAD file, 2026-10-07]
mechanical/tekno-pop-motor-mounts-wip/r2d2_inboard_axle_keeper_plate.stl
18.0 x 38.0 x 2.50

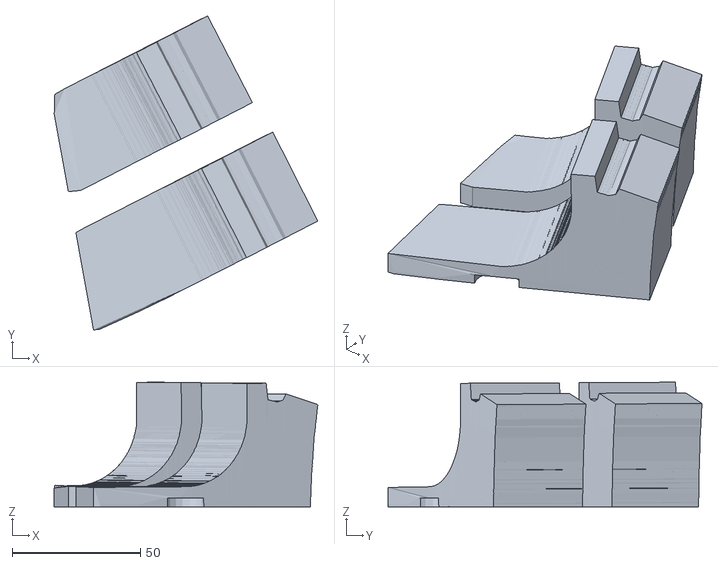
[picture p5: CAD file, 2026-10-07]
mechanical/tekno-pop-motor-mounts-wip/case_bottom_locators_only.stl
102.6 x 122.2 x 48.5

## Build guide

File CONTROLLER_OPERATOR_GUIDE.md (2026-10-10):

# FlySky FS-i6X Controller Layout & Operator Guide

> **Safety Notice:** Do not connect this wiring to the old ESP32-only firmware. Flash both the Teensy 4.1 body controller and the AstroPixels Plus ESP32 with the current firmware before combined testing; nothing counts as bench-verified until the commissioning record is filled in.

This guide details the function, channel mappings, and operational procedures for every switch, knob, and stick on your **FlySky FS-i6X 10-Channel 2.4GHz Transmitter** when operating R2-D2.

---

## 1. Visual Layout & Controls Overview

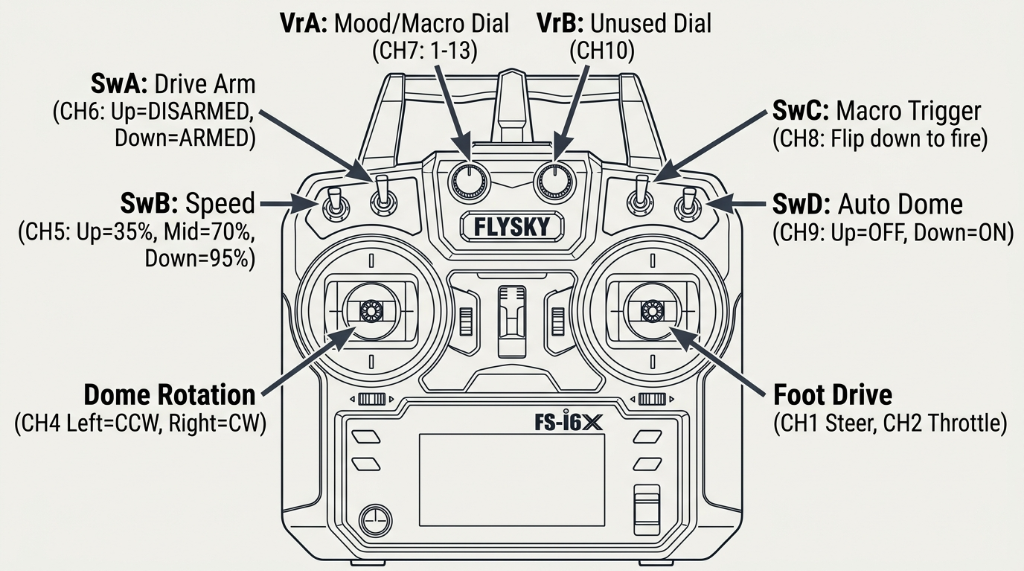
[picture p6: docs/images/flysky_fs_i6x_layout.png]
FlySky FS-i6X Controller Layout


```
       [ SwA ] (2-pos)                         [ SwD ] (2-pos)
     Drive Safety Arm                        Auto Dome Enable
        UP: Disarmed                            UP: Manual only
       DOWN: Armed                             DOWN: Auto wandering
           \                                       /
      [ SwB ] (2-pos)                         [ SwC ] (3-pos)
     Macro Fire Trigger                      Speed Rate Cap
       UP: Idle                                UP: 35% (Slow)
     DOWN: Fire Selected Macro                MID: 70% (Cruise)
                                             DOWN: 95% (Full)
           \         ( VrA )         ( VrB )       /
                     Mood/Macro       Unused
                      Selector        (CH10)
                      (13 pos)           |
                         \              /
            ┌──────────────────────────────────┐
            │   [Left Stick]    [Right Stick]  │
            │   Dome Rotation     Foot Drive   │
            │   ◄- CCW  CW -►   ◄-Turn  Turn-► │
            │                    ▲ Fwd   Rev ▼ │
            │                                  │
            │          ┌────────────┐          │
            │          │  LCD Screen│          │
            │          └────────────┘          │
            │          [Power Switch]          │
            └──────────────────────────────────┘
```

---

## 2. Quick Reference Summary Table

| Control | Type | iBus Channel | Function | Default Safe Position |
| :--- | :--- | :--- | :--- | :--- |
| **Right Stick (Y)** | Vertical Axis | **CH2** | **Forward / Reverse Drive** | Centered (Stop) |
| **Right Stick (X)** | Horizontal Axis | **CH1** | **Left / Right Steering** | Centered (Straight) |
| **Left Stick (X)** | Horizontal Axis | **CH4** | **Dome Rotation** (Left=CCW, Right=CW) | Centered (Stop) |
| **Left Stick (Y)** | Vertical Axis | **CH3** | *Unused* (Retired manual tilt) | Centered |
| **Switch SwA** | 2-Position Toggle (Top Left) | **CH6** | **Drive Safety Arm** (UP=Disarmed, DOWN=Armed) | **UP** (Disarmed) |
| **Switch SwC** | 3-Position Toggle (Inner Right) | **CH5** | **Speed Rate Cap** (UP=35%, MID=70%, DOWN=95%) | **UP** (35% Slow) |
| **Knob VrA** | Rotary Dial (Left Knob) | **CH7** | **Mood & Macro Selector** (13 Positions) | **Pos 1** (Dome Home) |
| **Switch SwB** | 2-Position Toggle (Inner Left) | **CH8** | **Macro Fire Trigger** (Flip DOWN to activate) | **UP** (Idle) |
| **Switch SwD** | 2-Position Toggle (Top Right) | **CH9** | **Auto Dome Enable** (UP=Off, DOWN=On) | **UP** (Off) |
| **Knob VrB** | Rotary Dial (Right Knob) | **CH10** | *Unused* (Reserved for expansion) | Any |

---

## 3. Control Operations & Detailed Functions

### 🕹️ Right Stick — Foot Drive & Steering
The right stick controls R2-D2's feet using single-stick arcade drive:
* **Push UP:** Drive forward.
* **Pull DOWN:** Drive in reverse.
* **Push LEFT:** Steer left (spins left wheel backward, right wheel forward when stationary).
* **Push RIGHT:** Steer right (spins right wheel backward, left wheel forward when stationary).
* **Release to Center:** Both wheels brake at the commissioned brake current. Partially easing off the stick slows the wheels at the commissioned slew rate rather than stepping the duty down, so a tall droid is not pitched forward.
* **On-Board Mixing:** The Teensy 4.1 controller automatically mixes throttle and steering in real-time at 50Hz, scaling both wheels proportionally so turns remain smooth without spinning out or clipping.

---

### 🕹️ Left Stick — Dome Rotation
The left stick gives direct manual control over the dome's continuous rotation servo once the servo neutral has been commissioned and saved (until then the dome servo receives no signal at all):
* **Push LEFT:** Spin dome counter-clockwise (CCW).
* **Push RIGHT:** Spin dome clockwise (CW).
* **Release to Center:** The dome halts and holds its position.
* **Speed Modulation:** The further you push the stick, the faster the dome spins. Gentle deflection gives smooth, slow cinematic rotation.
* **Up / Down Axis (CH3):** Unused. Manual holo projector tilt was retired to prevent servo strain; holos are automated.

---

### 🛡️ Switch SwA — Drive Safety Arm (Motion Interlock)
Located on the far top-left. This is your primary safety switch:
* **UP (<= 1250µs): DISARMED (Safe State)**  
  The motor controllers (VESCs) are completely inhibited. The droid will not move even if you bump the right stick. Always start with SwA UP.
* **DOWN (>= 1750µs): ARMED (Drive Enabled)**  
  Enables foot drive.
* **500ms Neutral Arming Interlock:**  
  To prevent unexpected movement, the controller will **not** arm if the stick is pushed while flipping the switch! You must:
  1. Have SwA UP.
  2. Leave the right stick completely centered.
  3. Flip SwA DOWN.
  4. Keep the stick centered for at least **500 milliseconds**.  
  Only then will drive engage. If a motor fault or radio hiccup occurs, SwA automatically disarms and requires repeating this sequence.

---

### ⚡ Switch SwC — Speed Rate Limiter (Triple Rates)
Located on the inner top-right. On a stock FS-i6X, SwC is the only 3-position switch, so assign it to **CH5** in the transmitter's Aux Channels menu. It sets the maximum driving speed (a lower cap is approached at the commissioned slew rate, not stepped to):
* **UP (Position 1, <= 1250µs): 35% Speed (Low / Safe Mode)**  
  Capped at 35% duty. Perfect for indoor driving, navigating crowded events, narrow doorways, and workbench testing.
* **CENTER (Position 2, ~1500µs): 70% Speed (Cruising Mode)**  
  Capped at 70% duty. Smooth, comfortable outdoor cruising speed.
* **DOWN (Position 3, >= 1750µs): 95% Speed (High Performance)**  
  Capped at 95% maximum electrical duty. Full acceleration and speed for open pavement.

---

### 🎭 Knob VrA — Mood & Routine Selector (13 Positions)
Located on the top face, left knob. Rotating this knob selects which sound, mood, or autonomous routine is queued:

| Position | Dial Turn | Routine Name | Sound / Action Description |
| :---: | :--- | :--- | :--- |
| **1** | Full CCW | **Home Dome** | Automatically rotates dome to 0° Front center using Hall sensor (`:DMH` + Track 11) |
| **2** | ~8% | **Movie Normal** | Standard inquisitive movie chatter (Bank 1) |
| **3** | ~15% | **Happy Melodic** | Cheerful, upbeat melodic trills and chirps (Bank 3) |
| **4** | ~23% | **Scream Routine** | Loud panic scream (`:SE01` + Track 102) with rapid holo-projector twitching and red LED flicker |
| **5** | ~31% | **Cantina Band** | Plays full *Cantina Band* song (`:SE05` + Track 106) with choreographed holo-projector dance |
| **6** | ~38% | **Princess Leia** | With SwD ON, aligns dome forward first; then plays the 1977 Leia distress message (`:SE08` + Track 109) with blue holo flicker |
| **7** | ~46% | **Star Wars Disco** | Upbeat disco celebration (`:SE09` + Track 110) with rainbow logic display animations |
| **8** | ~54% | **Short Circuit / Faint** | R2 plays power-down sound (`:SE06` + Track 107), logic lights black out, dome halts |
| **9–13** | ~62% to Full CW | **Chatter Banks** | Plays a random astromech conversational whistle or chirp |

The 13 positions are equal ~77µs bands over 1000–2000µs, so position 13 is reachable with the knob fully clockwise.

---

### 🎯 Switch SwB — Routine Trigger
Located on the inner top-left; assign it to **CH8**. This switch executes whatever routine is selected on **Knob VrA**:
* **UP (Idle):** Resting position.
* **Flip DOWN (> 1750µs):** **FIRES** the selected routine!
* **Reset:** To trigger another routine, return SwB to the UP position, adjust knob VrA if desired, and flip DOWN again.

---

### 🤖 Switch SwD — Autonomous Dome Wandering
Located on the far top-right:
* **UP (<= 1250µs): OFF**  
  Autonomous dome wandering is disabled. The dome only rotates when you touch the left stick.
* **DOWN (>= 1750µs): ON**  
  Autonomous lifelike behavior enabled once auto dome is commissioned (references and timing saved). When R2-D2 is parked and untouched for more than **20 seconds**, the dome homes to the front, then glances up to ±45° and returns, like a real astromech.
* **Manual Override:** Touching the left stick or driving immediately cancels autonomous movement and hands full control back to you.

---

## 4. Safe Operating Procedure (Power-On Checklist)

Follow this routine every time you operate R2-D2:

1. **Pre-Flight Switch Check:**
   - SwA **UP** (Disarmed)
   - SwB **UP** (Trigger Released)
   - SwC **UP** (35% Low Speed)
   - SwD **UP** (Auto Dome Off)
   - Both joysticks resting at center.
2. **Turn On Transmitter:** Slide the center power switch UP. Confirm the LCD screen illuminates and battery voltage is above 9.0V.
3. **Turn On Droid:** Engage R2-D2's master cutoff switch. Verify logic displays light up; the startup chime (Track 255) plays once the dome and body link up.
4. **Arming to Drive:**
   - Ensure wheels are on the ground in an open area.
   - Keep right stick centered.
   - Flip **SwA DOWN**.
   - Wait **1 second** (Teensy verifies 500ms neutral stick handshake).
   - Gently push the right stick forward to drive!
5. **Emergency Stop (E-Stop):**
   - **Stop:** Release the right stick (wheels brake at the commissioned brake current).
   - **Kill Motion:** Flip **SwA UP** (disarms both feet; they brake and stay disarmed).
   - **Web STOP:** The dashboard STOP button latches a body STOP for feet and dome. It stays latched until **Release STOP** is pressed with SwA UP and all sticks centred for 500ms.
   - **Physical Cutoff:** Push the master cutoff switch on the droid's body.

---

## 5. Transmitter Failsafe Verification

The FS-iA6B receiver is programmed with a fail-safe configuration:
* If the transmitter runs out of batteries or goes out of range, the receiver automatically outputs:
  - CH1 (Steering) = `1500µs` (Centered)
  - CH2 (Throttle) = `1500µs` (Centered)
  - CH4 (Dome) = `1500µs` (Centered)
  - CH6 (SwA) = `1000µs` (UP / DISARMED)
  - CH8 (SwB) = `1000µs` (UP / Idle)
  - CH9 (SwD) = `1000µs` (UP / Off)
* FlySky receivers keep sending iBUS frames after signal loss, carrying these failsafe values, so the Teensy sees CH6 OFF and disarms both feet. Without the CH4 failsafe the receiver would hold the last dome stick position and keep the dome turning.
* If frames stop entirely (receiver unplugged or unpowered), the Teensy treats RC as stale after **250ms** and disarms. Re-arming always needs SwA UP, then DOWN, with the sticks centred for 500ms.

### Guided radio check (`/commissioning`)

The dome's commissioning page has a **Start radio check** button. It walks through every control and then the failsafe, so you can confirm the channel mapping above without a laptop. Keep the wheels raised (SwA goes DOWN during the check), and watch the Radio line, which updates by itself with each new prompt. Complete each prompt within 15 s:

1. With SwA UP (CH6 OFF): right stick UP (CH2), then right stick RIGHT (CH1), then left stick RIGHT (CH4). A stick prompt does not count while SwA is DOWN.
2. SwA DOWN (CH6), SwC through all three positions (CH5), SwB DOWN (CH8), SwD DOWN (CH9). SwB macros are suppressed while the check is prompting, so SwB DOWN fires nothing here; if SwB is still DOWN when the check ends, flip it UP before the next macro. If auto dome is already saved and SwD was UP, SwD DOWN arms auto dome and the dome may turn: keep clear.
3. VrA knob fully one way and then the other (CH7).
4. Set SwA, SwB and SwD DOWN, then **turn the transmitter OFF**.

The check passes when the receiver's failsafe frames show the sticks centred and CH6/CH8/CH9 low. If the receiver stops sending frames instead, the result reads "receiver stops output". The Teensy still disarms on stale radio, but the receiver has no failsafe values set. Wrong values fail the check: set the failsafe as listed above and run it again. Turn the transmitter off for the last step. Flipping the switches back UP with the transmitter on can look like a pass. The **Audio check** button next to it plays track 255 and passes when the DFPlayer confirms playback.

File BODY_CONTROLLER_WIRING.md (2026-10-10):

# Teensy Body Controller Wiring

> **Safety Notice:** Do not connect this wiring to the old ESP32-only firmware. Flash both the Teensy 4.1 body controller and the AstroPixels Plus ESP32 with the current firmware before combined testing; nothing counts as bench-verified until the commissioning record is filled in.

The body controller is a **Teensy 4.1 in the Treedix socketed screw-terminal carrier [B09NXYWYK7](https://www.amazon.ca/dp/B09NXYWYK7)**. The AstroPixels ESP32 controller resides in the dome.

Use [Power Harness Guide](POWER_HARNESS_GUIDE.md) for power wiring, [Dome Wiring](DOME_WIRING_DIAGRAM.md) for PCA9685 and lighting, and [Commissioning](BODY_CONTROLLER_COMMISSIONING.md) for checks before motion.

## 1. Mounting and connector rules

Mount the carrier on standoffs in the body beside the receiver and body shifter. Leave room to reach the screw terminals, USB socket and Teensy's Program button. Keep motor phase cables and the amplifier away from receiver antennas and signal wiring.

Teensy plugs into the carrier sockets. If its male headers are not installed, solder the matching headers before inserting it. No perfboard or separate female sockets are needed. With power disconnected, confirm carrier labels by continuity to the corresponding Teensy pins; do not count terminal positions from a photograph.

Use short 22AWG copper signal/ground leads, properly sized ferrules at screw terminals, and labelled detachable device connectors. Use keyed connectors where available. Do not leave loose Dupont jumpers as the permanent harness. Confirm device pin labels before inserting each connector: a reversed three-pin plug can put 5V on a signal input.

Servo and motor power go through distribution wiring, not the Teensy carrier. Never solder-tin stranded ends that enter screw terminals. Clamp cables beside the carrier so pulling a harness does not pull its terminals.

## 2. Approved 5V power branches

Use the owned screw-terminal distribution and four inline holders [B0FDJYRGB7](https://www.amazon.ca/dp/B0FDJYRGB7). No separate 5V fuse boxes.

| Circuit | Load | Fuse | Feed / return |
| --- | --- | --- | --- |
| B-SERVO | Body dome-rotation servo | 5A | 16AWG to factory servo cable |
| B-LOGIC | Teensy, receiver, DFPlayer, body shifter | 2A | 18AWG shared feed; device leads below |
| D-SERVO | PCA9685 V+ / six holo servos | 5A | 16AWG to screw terminals |
| D-LOGIC | AstroPixels, Hall sensor, dome shifter | 3A | 18AWG motherboard feed; 22AWG sensor/reference leads |

Each fuse goes in the positive lead at the distribution takeoff. Grounds remain unfused. The electronics fuse output feeds an **insulated fan-out separate from the unfused positive bus**. Do not return its output to the same bus: that bypasses the fuse. Use unused isolated terminal positions or an insulated multiwire connector to make the fused fan-out.

Body device feeds: Teensy VIN/GND 22AWG, receiver 5V/GND 22AWG, DFPlayer VCC/GND 20AWG, shifter HV/GND 22AWG. Keep these short. Use the manufacturer's installed device leads rather than replacing them with thinner extensions.

Body and dome 5V positive rails never connect together. All grounds connect. Both bucks' negative outputs and inputs share the common ground; the converters are non-isolated.

## 3. Teensy carrier terminal map

UARTs cross: **TX at one device goes to RX at the other**. Both VESCs and DFPlayer have separate ground connections to body ground.

| Teensy terminal | Interface | Connect to | Signal |
| --- | --- | --- | --- |
| 1 | Serial1 TX | Left VESC COMM RX | 115200, 3.3V |
| 0 | Serial1 RX | Left VESC COMM TX | 115200, 3.3V |
| 8 | Serial2 TX | Right VESC COMM RX | 115200, 3.3V |
| 7 | Serial2 RX | Right VESC COMM TX | 115200, 3.3V |
| 14 | Serial3 TX | 1k ohm resistor, then DFPlayer RX | 9600, 3.3V |
| 15 | Serial3 RX | DFPlayer TX | 9600, 3.3V |
| 17 | Serial4 TX | Slip ring BODY CH3 | 115200, 3.3V |
| 16 | Serial4 RX | Slip ring BODY CH6 | 115200, 3.3V |
| 21 | Serial5 RX | Body shifter LV1 | 115200 iBUS input |
| 24 | Serial6 single-wire TX/RX | Body shifter LV2 | 115200 iBUS telemetry |
| 2 | Dome servo pulses | Body shifter LV3 | 50Hz servo pulses |
| VIN | Power input | B-LOGIC fused 5V | Regulated 5V |
| GND | Ground | Body ground distribution | Common reference |
| 3.3V | Reference supply | Body shifter LV | 3.3V |

**14 Teensy terminal connections:** 11 signal terminals plus VIN, GND and 3.3V. Serial5 TX20 and Serial6 RX25 are unused. Serial7/8 remain spare. USB diagnostics use no UART pins.

Only shifter LV is powered from Teensy 3.3V. Do not power receiver, servo or DFPlayer from Teensy output pins. Teensy signal pins are **not 5V tolerant**.

## 4. Selected logic shifters

Use **Lonely Binary [B0FFMLDYNY](https://www.amazon.ca/dp/B0FFMLDYNY)**: one four-channel module in the body and another in the dome. The old converters are being returned. No Pololu or TXS0108E substitution is part of this design.

The diagrams call low-side channels LV1-LV4 and high-side channels HV1-HV4. On boards labelled A/B, these mean **A1-A4 / B1-B4** respectively. Follow actual PCB labels, not left/right orientation.

These modules contain 10k ohm pull-ups; LV and HV are voltage **inputs**, not regulator outputs. They do not generate 3.3V. The [manufacturer documents 115200-baud serial with short jumpers](https://learn.lonelybinary.com/manuals/llc/the-slow-rising-edge).

| Body shifter | Connection |
| --- | --- |
| LV | Teensy 3.3V |
| HV | B-LOGIC fused 5V |
| GND | Body ground |
| HV1 / B1 | Receiver iBUS SERVO signal |
| LV1 / A1 | Teensy RX21 |
| HV2 / B2 | Receiver iBUS SENSOR signal |
| LV2 / A2 | Teensy pin 24 |
| LV3 / A3 | Teensy pin 2 |
| HV3 / B3 | Dome-rotation servo signal |
| Channel 4 | Unconnected |

The dome shifter uses dome fused D-LOGIC 5V at HV, ESP32 3.3V at LV and dome ground at GND. Front Hall signal goes to HV2/B2 (LV2/A2 to GPIO19); Rear Hall signal goes to HV3/B3 (LV3/A3 to GPIO18). Channels 1 and 4 are unused.

### Receiver power and input

Mount the FS-iA6B in the body. Feed its labelled positive/negative supply pins from B-LOGIC 5V and body ground. Its SERVO and SENSOR connectors share supply pins internally: one supply connection is enough; additional cables need signal and ground, not another power source.

SERVO is the receiver's **channel-data output**, not our dome servo connection. Teensy listens on RX21. Do not connect TX20 to that output.

### Single-wire telemetry

```text
Receiver SENSOR data <--> Body HV2/B2 | LV2/A2 <--> Teensy pin 24
Receiver ground -------- Body ground ----------- Teensy GND
```

The receiver polls; Teensy replies and releases the same wire. Teensy uses native half-duplex plus open drain:

```cpp
Serial6.begin(115200, SERIAL_8N1_HALF_DUPLEX);
Serial6.setTX(24, true);
```

RX25 is unused. Do not join separate push-pull TX/RX pins. Put the shifter beside Teensy/receiver and use short leads. No oscilloscope or logic analyzer is required; commissioning uses channel counters, telemetry replies and the handheld display.

Teensy supplies external pack voltage from the lower of two fresh VESC readings and the hottest VESC MOSFET temperature. FS-CVT01 is unused; F6 is empty. Neither eRPM nor voltage is a road-speed or battery-percentage measurement.

## 5. Direct VESC and audio links

Connect TX/RX/GND on **each** COMM connector. VESC power pins 5V/3.3V and ADC/ADC2 stay unconnected. Leave RECEIVER/SIN, CAN and SWD unused. Set the internal CAN switch OFF. There is one shared VESC battery power pair, not one per wheel.

Both VESC UART links are 3.3V and bypass shifters. Configure each controller separately in [VESC Drive Setup](VESC_DRIVE_INTEGRATION.md).

DFPlayer VCC uses body fused 5V, but its UART is **3.3V**. Connect Teensy TX14 through the 1k ohm resistor to DFPlayer RX; connect DFPlayer TX directly to Teensy RX15. Do not put a shifter in this UART. BUSY is unconnected in version 1.

## 6. Slip ring and dome link

Use end-to-end continuity to identify the six contacts; wire colours alone do not establish channel numbers.

| Contact | BODY end | DOME end | Function |
| --- | --- | --- | --- |
| CH1 | F4 7.5A fused battery positive | Dome buck IN+ | Dome 12V feed |
| CH2 | Body ground bus | Dome ground / buck IN- | Common return |
| CH3 | Teensy TX17 | ESP32 GPIO16 | Body to dome serial |
| CH4 | Unconnected | Unconnected | Spare |
| CH5 | Unconnected | Unconnected | Spare |
| CH6 | Teensy RX16 | ESP32 GPIO17 | Dome to body serial |

Serial is 115200, 8N1, two-way 3.3V, no shifter. Use AstroPixels' dedicated serial RX16/TX17 connections; do not connect a serial-header 5V pin. Ring CH2 provides common ground. Insulate both ends of CH4/CH5 separately and label SPARE.

GPIO5/AUX3 and GPIO4/AUX2 are spare. GPIO19 is Front Hall input, GPIO18 is Rear Hall input. GPIO21/22 remain I2C. The radio receiver, VESC motor controllers, audio player, and dome rotation servo connect directly to the Teensy in the body.

## 7. First-time harness assembly

Work with battery, USB and charger disconnected. Label both ends before terminating.

| Harness | Assemble | Unpowered check |
| --- | --- | --- |
| TEENSY-POWER | B-LOGIC 5V -> VIN; GND -> ground | Correct carrier terminals; no VUSB/VIN re-bridge |
| RADIO-IBUS | SERVO -> shifter channel 1 -> RX21 | No TX20 connection |
| RADIO-SENS | SENSOR -> shifter channel 2 -> pin 24 | One signal wire; RX25 unused |
| LEFT-VESC | TX1 -> RX; TX -> RX0; ground | VESC supply pins unconnected |
| RIGHT-VESC | TX8 -> RX; TX -> RX7; ground | Separate from left UART |
| AUDIO-UART | TX14 -> 1k resistor -> RX; TX -> RX15 | Resistor only in command line |
| DOME-SERVO | B-SERVO 5V/GND; shifter HV3 signal | Power off carrier; gear initially disengaged |
| DOME-LINK | CH3 / CH6 UART, CH1 / CH2 supply | Contact continuity; CH4/5 insulated |

Perform [VUSB/VIN isolation and commissioning](BODY_CONTROLLER_COMMISSIONING.md) before combining USB and externally powered VIN. Cutting the link is a one-time modification; Teensy stays installed for subsequent USB programming.

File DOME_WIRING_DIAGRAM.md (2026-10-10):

# Body/Dome Wiring and AstroPixels Connections

> **Safety Notice:** Do not connect this wiring to the old ESP32-only firmware. Flash both the Teensy 4.1 body controller and the AstroPixels Plus ESP32 with the current firmware before combined testing; nothing counts as bench-verified until the commissioning record is filled in.

Use [Body Controller Wiring](BODY_CONTROLLER_WIRING.md) for Teensy terminals and [Power Harness](POWER_HARNESS_GUIDE.md) for exact fuse/distribution wiring. The [interactive inspector](wiring_visualizer.html) is the terminal graph.

## 1. Body components

Mount Teensy 4.1/Treedix, FS-iA6B receiver, body Lonely Binary four-channel shifter, DFPlayer and dual VESC in the body. The dome-rotation servo also stays in the body.

Body buck OUT+ feeds two branches: B-SERVO 5A for dome servo and B-LOGIC 2A for Teensy VIN, receiver, DFPlayer and body shifter HV. Teensy 3.3V supplies shifter LV. Grounds common. Body shifter channels: receiver SERVO ->HV1/LV1->RX21; receiver SENSOR <->HV2/LV2<->pin 24; pin 2->LV3/HV3->dome servo signal. Fourth channel unused.

Each VESC gets direct3.3V TX/RX/GND: left TeensyTX1/RX0, right TX8/RX7. No CAN master/slave forwarding; internal CAN switch OFF. TeensyTX14->1k resistor->DFPlayerRX; DFPlayerTX->RX15.

## 2. Slip ring

| Contact | BODY end | DOME end | Function |
| --- | --- | --- | --- |
| CH1 | F4 7.5A fused battery positive | Dome buck IN+ | Dome 12V feed |
| CH2 | Body ground bus | Dome ground / buck IN- | Common return |
| CH3 | Teensy TX17 | ESP32 GPIO16 | Body to dome serial |
| CH4 | Unconnected | Unconnected | Spare |
| CH5 | Unconnected | Unconnected | Spare |
| CH6 | Teensy RX16 | ESP32 GPIO17 | Dome to body serial |

Verify numbering end-to-end with a multimeter. Insulate CH4/5 separately at both ends. CH3/6 use3.3V1152008N1; no translator. GPIO16/17 are the dedicated AstroPixels serial pins. Leave the header voltage pin disconnected;5V must never enter a UART pin.

## 3. Dome power and selected shifter

CH1/2 -> dome buck IN+/IN-. Buck OUT+/OUT- -> owned dome 5V/GND terminal groups using12AWG trunks. D-LOGIC3A feeds AstroPixels 5V screw terminal, Hall supply and shifter HV; D-SERVO 5A separately feeds PCA V+.

Use a four-channel **Lonely Binary B0FFMLDYNY** module. HV/LV are externally supplied references, not regulator outputs.

| Dome shifter terminal | Wire |
| --- | --- |
| HV | D-LOGIC fused 5V |
| LV | ESP32 3.3V |
| GND | Dome ground |
| HV2 / B2 | KY-003 Front Hall signal (0°) |
| LV2 / A2 | GPIO19 / AUX5 |
| HV3 / B3 | KY-003 Rear Hall signal (180°) |
| LV3 / A3 | GPIO18 / AUX4 |
| Channels 1/4 | Unconnected |

Two KY-003 Hall sensors (Front 0° and Rear 180°) detect the single dome ring magnet. Hall VCC is D-LOGIC 5V and ground is dome ground. Set/record detected polarity during commissioning. Hall state is sent to Teensy every 20ms / on change for body-controlled homing and calibration.

## 4. PCA9685: separate logic and servo power

The AstroPixels I2C header letters are **G** ground, **V** supply, **C** clock, **D** data. Its voltage header pin is not the PCA logic supply.

| AstroPixels / source | PCA9685 terminal |
| --- | --- |
| I2C D / GPIO21 | SDA |
| I2C C / GPIO22 | SCL |
| I2C G | Logic GND |
| ESP32 3.3V | VCC |
| D-SERVO 5A fused 5V | V+ screw terminal |
| Dome ground,16AWG | Ground screw terminal |

**Leave I2C V disconnected.** No level shifter on I2C. Logic ground and servo ground are common on PCA9685; the heavy return still goes directly to its ground screw terminal, not through the small I2C ground lead.

### Servo Header Pinout & 3-Pin Connector Installation

The PCA9685 driver is configured at default I2C address **0x40** with 50Hz PWM servo output. Each channel on the PCA9685 provides a standard 3-pin 0.1" (2.54mm) male header in three rows:
- **`S` / PWM (Signal row):** Pulse signal from PCA9685 channel
- **`+` / V+ (Center row):** +5V servo power, connected internally across the PCB to the green V+ screw terminal
- **`-` / GND (Ground row):** Common ground, connected internally across the PCB to the green GND screw terminal

Each of the six MG90S holoprojector servos plugs **directly onto its 3-pin channel header** using its standard factory 3-pin connector. Do **not** splice servo power/ground together or run separate wires to the screw terminals; the PCA9685 board's internal copper plane distributes 5V power and ground from the screw terminal to all 16 channel headers.

| PCA Channel | Servo | Connection |
| :---: | :--- | :--- |
| **0** | Front pan | Direct 3-pin servo plug (Signal, V+, GND) |
| **1** | Front tilt | Direct 3-pin servo plug (Signal, V+, GND) |
| **2** | Rear pan | Direct 3-pin servo plug (Signal, V+, GND) |
| **3** | Rear tilt | Direct 3-pin servo plug (Signal, V+, GND) |
| **4** | Top pan | Direct 3-pin servo plug (Signal, V+, GND) |
| **5** | Top tilt | Direct 3-pin servo plug (Signal, V+, GND) |
| **6–15** | Unused | Leave unconnected |

Test one servo at a time with horns removed, calibrate travel before mounting, then test all six without hitting mechanical stops. Check for mechanical binding or excessive heating. If a fuse blows, investigate and resolve mechanical binding or short circuits rather than increasing the fuse rating.

## 5. ESP32 signal map

| Pin | Target function / AstroPixels connection |
| --- | --- |
| GPIO16 | Serial2 RX; ringCH3 from TeensyTX17 |
| GPIO17 | Serial2 TX; ringCH6 to TeensyRX16 |
| GPIO18 | Rear Hall through dome shifter channel 3 / AUX4 |
| GPIO19 | Front Hall through dome shifter channel 2 / AUX5 |
| GPIO21 | I2C SDA / D |
| GPIO22 | I2C SCL / C |
| GPIO15 | Front logic displays / FLD |
| GPIO33 | Rear logic display / RLD |
| GPIO32 | Front PSI / FPSI |
| GPIO23 | Rear PSI / RPSI |
| GPIO25 | Front holo LED / FHP |
| GPIO26 | Rear holo LED / RHP |
| GPIO27 | Top holo LED / THP |
| GPIO2/4/5 | Unused / spare |

The dedicated body protocol is the sole Serial2 reader at 115200. The firmware migration has disabled the old MarcDuino serial reader on that UART; web/internal command dispatch remains. GPIO5 is no longer a UART input, avoiding use of a boot-strapping pin.

## 6. Programming and test order

Flash ESP32 **removed from AstroPixels**, then unplug USB before reinstalling with all power off. Never let a computer USB port power assembled lights/servos. Installed ESP32 updates use the acknowledged maintenance/OTA path.

Teensy uses external VIN with the factory VUSB/VIN link cut once and carrier checked for re-bridging; ordinary USB then supplies data/debug only. See the official cut illustration and exact continuity checks in [Commissioning](BODY_CONTROLLER_COMMISSIONING.md).

First power logic only; validate UART/Hall/I2C before adding servo power. Rotate dome through full turns while watching communication counts/errors. Complete the failure matrix and unloaded motion checks before engaging drive gears or floor testing.

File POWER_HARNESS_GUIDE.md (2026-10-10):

# R2-D2 Power Harness: Assembly and Fuse Schedule

> **Safety Notice:** Do not connect this wiring to the old ESP32-only firmware. Flash both the Teensy 4.1 body controller and the AstroPixels Plus ESP32 with the current firmware before combined testing; nothing counts as bench-verified until the commissioning record is filled in.

This is the approved first-assembly schedule. Use [Body Controller Wiring](BODY_CONTROLLER_WIRING.md) for the exact Teensy terminals and [Commissioning](BODY_CONTROLLER_COMMISSIONING.md) before applying motion. The [interactive inspector](wiring_visualizer.html) supplies terminal-to-terminal wiring.

## 1. Main supply

| Part | Selection / connection |
| --- | --- |
| Battery | Renogy RBT1220LFP-TM, nominal12.8V20Ah LiFePO4;20A continuous limit |
| Main positive | Battery ->25A main fuse -> accessible master cutoff ->12V fuse block;10AWG |
| Main fuse location | Within 150mm of battery positive;10AWG holder rated >=30A /32V DC |
| Cutoff | DC load-break rated >=30A at >=16V; reachable outside droid |
| Main negative | Battery -> fuse block negative bus;10AWG, unfused |
| Fuse block | One six-way automotive blade block with integrated negative bus |
| Bucks | Two fixed5V10A [B09T954ZV1](https://www.amazon.ca/dp/B09T954ZV1), one body/one dome; listed input 10-35V |
| Slip ring | Six contacts,10A/contact,17AWG installed leads;16AWG power extensions |

Fuses across the power harness are sized as best estimates based on planned draw for each subsystem. Total continuous battery draw should be kept within the 20A battery rating by configuring motor limits in VESC Tool and accounting for lighting, audio, and servo loads.

## 2. Approved fuse schedule

### Main and 12V fuse block

| Circuit | Load | Fuse | Copper wire / return |
| --- | --- | --- | --- |
| MAIN | Fuse block through cutoff | 25A | 10AWG |
| F1 | Dual VESC shared battery input | 15A | 12AWG |
| F2 | Empty spare | None | No connection |
| F3 | Body buck IN+ | 7.5A | 16AWG to buck; ground to negative bus |
| F4 | Dome buck IN+ through ring CH1 | 7.5A | 16AWG extensions; CH2 ground return |
| F5 | HF82 amplifier power | 5A | 18AWG |
| F6 | Empty spare | None | FS-CVT01 unused |

F1 powers **one shared VESC input pair**; do not add a second supply to a COMM or RECEIVER connector. Do not parallel F1/F2 or ring contacts.

### Four local 5V inline fuses

| Circuit | Load | Fuse | Feed / return |
| --- | --- | --- | --- |
| B-SERVO | Body dome-rotation servo | 5A | 16AWG to servo factory leads |
| B-LOGIC | Teensy, receiver, DFPlayer, body shifter | 2A | 18AWG fan-out feed;20/22AWG short device leads |
| D-SERVO | PCA9685 V+ / six holo servos | 5A | 16AWG to PCA screw terminals |
| D-LOGIC | AstroPixels, Hall sensor, dome shifter | 3A | 18AWG motherboard;22AWG short sensor/reference leads |

Use the four owned standard blade inline holders [B0FDJYRGB7](https://www.amazon.ca/dp/B0FDJYRGB7), with 12AWG holder leads. No separate 5V fuse boxes. The indexed included assortment starts at 5A: obtain matching **standard ATO/ATC2A and3A**, not mini-blade fuses. Fit two 5A, one 2A and one 3A; keep matching spares.

Put every fuse in the positive branch **at its takeoff, before the smaller cable**. Use a correctly sized reducing crimp to join holder leads to the branch. Do not force a12AWG holder lead into an undersized terminal. Ground branches remain unfused.

### Make the owned terminal blocks into the required groups

The uxcell dual-row strip may connect each opposite pair of screws, not every terminal in a row. With all power disconnected:

1. Measure continuity between opposite screws and adjacent positions. Identify the actual connections.
2. Reserve isolated positions for positive, ground and fused-electronics fan-out. Label them.
3. Join the intended positive positions with 12AWG copper jumpers; separately join intended ground positions. Confirm no positive-to-ground continuity.
4. Buck OUT+ -> unfused local positive group; buck OUT- -> ground group. Use12AWG trunks.
5. Positive takeoff -> servo inline fuse -> servo supply. Positive takeoff -> electronics inline fuse -> **a separate insulated fused-electronics fan-out**.
6. Connect electronics only to the fused fan-out. **Do not jumper its output back to the unfused positive group**: that defeats the fuse.

Use available isolated positions or insulated multiwire connectors for the small fused fan-outs. Existing blocks are retained; no new fuse box is needed.

```text
BODY buck OUT+ -> BODY unfused positive -> B-SERVO 5A -> body dome servo
                                      -> B-LOGIC 2A -> insulated logic fan-out
                                                       -> Teensy VIN
                                                       -> receiver5V
                                                       -> DFPlayer VCC
                                                       -> body shifter HV

DOME buck OUT+ -> DOME unfused positive -> D-SERVO 5A -> PCA9685 V+ terminal
                                      -> D-LOGIC3A -> insulated logic fan-out
                                                       -> AstroPixels 5V
                                                       -> Two Hall sensors 5V / dome shifter HV
```

The two 5V positive rails never join. Common ground connects throughout via ring CH2. These bucks are non-isolated; their input/output negatives are common.

### PCA9685 supply and servo checks

Run 16AWG from D-SERVO 5A to PCA9685 **V+ screw terminal** and 16AWG return to its ground screw. VCC is a separate 3.3V logic supply from ESP32. Do not feed servo power through I2C/header wiring.

Each servo plugs directly into its designated 3-pin channel header (Channels 0–5) using its factory 3-pin servo plug. The green screw terminal is exclusively for the main 16AWG 5V feed and ground return; the board's internal copper plane powers all 16 channel headers. Connect/test one servo at a time, then all six together through their calibrated travel. Check for mechanical binding, excessive heating, or travel limits. If a fuse blows, investigate and resolve mechanical binding or short circuits rather than increasing the fuse rating.

## 3. Slip ring

| Contact | BODY end | DOME end | Function |
| --- | --- | --- | --- |
| CH1 | F4 7.5A fused battery positive | Dome buck IN+ | Dome 12V feed |
| CH2 | Body ground bus | Dome ground / buck IN- | Common return |
| CH3 | Teensy TX17 | ESP32 GPIO16 | Body to dome serial |
| CH4 | Unconnected | Unconnected | Spare |
| CH5 | Unconnected | Unconnected | Spare |
| CH6 | Teensy RX16 | ESP32 GPIO17 | Dome to body serial |

Identify contacts by continuity, not colours. UART uses3.3V115200-baud8N1. No shifter or5V is attached to either signal contact. CH4/5 are insulated at **both** ends. Keep ring signal wiring separate from high-current motor cables.

## 4. Wire quantities and assembly

Measure actual paths before cutting; these are shopping allowances, not required run lengths.

| Copper gauge | Allowance | Use |
| --- | --- | --- |
| 10AWG | 4m red,2m black | Battery/main supply and return |
| 12AWG | 15m assorted | Six approximately2m phase runs, VESC supply and buck5V trunks |
| 16AWG | 6m red,6m black | Buck inputs, ring power extensions and servo trunks |
| 18AWG | 3m red,3m black | Amp supply, AstroPixels and electronics fan-outs |
| 20AWG | 2m red,2m black | DFPlayer power and speaker |
| 22AWG five-core | 5m | Two approximately2m Hall extensions |
| 22AWG singles | Measured short runs | UART, receiver supply, shifters, Hall and I2C |

Use stranded copper, not CCA. Secure battery, converters, fuse block and carriers before wiring. Protect shell holes with grommets; leave service loops at leg/shoulder joints. Keep phase wiring away from signal wiring and antennas. Crimp with the correctly sized tool, pull-test each crimp and insulate joints with heatshrink. Use ferrules at screw terminals; do not solder-tin those ends.

Converters and terminals need airflow and strain relief. Label both ends of each harness with circuit and connector pin names.

## 5. Audio power and signal path

HF82 TPA3110 amplifier [B09F2XR9MN](https://www.amazon.ca/dp/B09F2XR9MN) uses F5 battery power and common ground. DFPlayer uses B-LOGIC fused 5V.

```text
DFPlayer DAC_L -> input TRS tip -> BESIGN isolator -> output TRS tip -> amp LINE L
DFPlayer GND   -> input sleeve                    -> output sleeve  -> amp LINE GND
Amp L+ / L-   -> speaker + / -
```

Use the [BESIGN B06XQYN77L](https://www.amazon.ca/dp/B06XQYN77L) line isolator. Do not add an external sleeve jumper around it. TRS ring/right channel is unused for this mono connection.

Neither amplifier speaker output connects to ground; it is a bridge output. DFPlayer SPK1/SPK2 never go into an amplifier line input. Default digital volume 10/30 and Wi-Fi volume control replace a separate potentiometer.

The1k ohm resistor in Teensy TX14 -> DFPlayer RX is a serial command-line resistor, not a3.3V/5V converter.

## 6. Power-up sequence

Follow the detailed [commissioning procedure](BODY_CONTROLLER_COMMISSIONING.md).

First test continuity with all sources disconnected. Energize the main bus with loads disconnected, then F3/F4 with all four5V output fuses removed. Measure each buck output 4.9-5.1V. Turn off before adding loads.

Power electronics via B-LOGIC 2A/D-LOGIC3A before servos; do not plug computer USB into mounted ESP32. Teensy needs the approved VUSB/VIN cut and carrier isolation check before ordinary USB is used with external 5V.

Only after compatible firmware and individual subsystem checks: fit B-SERVO 5A/D-SERVO 5A, then F1 for unloaded VESC tests. Test transmitter-off, each lost UART and physical stop behaviour before floor driving. A capacitor is optional troubleshooting for observed supply transients, not a required purchase.

## 7. Charging

Use [ECO-WORTHY B09SYNQNC1](https://www.amazon.ca/dp/B09SYNQNC1),14.4V9A, **LiFePO4 mode**, through the supplied SAE ring-terminal harness with 10A inline fuse close to battery positive. Confirm SAE polarity with a meter before connection.

This charging harness attaches directly to the battery: master cutoff does not isolate it. Cutoff OFF while charging; unplug charger before driving or servicing. Never use lead-acid repair/desulfation modes or charge below0C. Protect the live SAE socket from shorts.

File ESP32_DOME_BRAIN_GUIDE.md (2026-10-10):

# AstroPixels Unified ESP32 Dome Brain Guide
## (FastLED Alternative Firmware Reference)

> **Historical reference only.** This ESP32-only wiring/code is incompatible with the approved Teensy body-controller build. Do not assemble its pin map, receiver-in-dome layout or CAN forwarding. Use [Body Controller Wiring](BODY_CONTROLLER_WIRING.md), [Dome Wiring](DOME_WIRING_DIAGRAM.md) and [Commissioning](BODY_CONTROLLER_COMMISSIONING.md). Firmware has been migrated to the Teensy/AstroPixels split architecture.

> [!NOTE]
> **Primary Firmware:** The recommended firmware for this project is [AstroPixels Plus Unified](ASTROPIXELS_PLUS_UNIFIED/README.md), which includes the mobile Wi-Fi dashboard, OTA updates, and ReelTwo lighting.
> This document describes the alternative standalone FastLED sketch ([`ASTROPIXELS_UNIFIED_BRAIN.ino`](ASTROPIXELS_UNIFIED_BRAIN.ino)), retained as an engineering reference.

---

## 1. System Architecture & Signal Flow

The dome ESP32 serves as the central brain for the entire droid, running all lights, 6 holoprojector servos, sound triggering, dome rotation, and foot motor drive. The dome-mounted FlySky receiver sends all radio channels over digital iBUS to the ESP32, which commands the Dual VESC controller over UART down the slip ring.

```mermaid
flowchart TB
    subgraph BODY [BODY ENCLOSURE]
        BATTERY["Fused 12V Battery Bus"]
        VESC["Dual VESC 4.20 (Internal CAN ON)"]
        BODY_BUCK["Body 5V Buck Converter"]
        MOTORS["Razor Hub Motors (Left & Right)"]
        DFPLAYER["DFPlayer Mini + HF82 Amp + Speaker"]
        DOME_SERVO["35kg Continuous Rotation Servo"]

        BATTERY --> VESC ==> MOTORS
        BATTERY --> BODY_BUCK --> DFPLAYER
        BODY_BUCK --> DOME_SERVO
    end

    subgraph RING [6-CHANNEL SLIP RING]
        CH1["CH1: Fused 12V to Dome Buck"]
        CH2["CH2: Common Ground"]
        CH3["CH3: VESC Telemetry UART (115,200 baud)"]
        CH4["CH4: Sound Serial (9,600 baud)"]
        CH5["CH5: Dome Servo PWM (3.3V)"]
        CH6["CH6: VESC Drive UART (115,200 baud)"]
    end

    subgraph DOME [DOME ENCLOSURE]
        RX["FlySky FS-iA6B Receiver (In Dome)"]
        ESP32["AstroPixels ESP32 Brain"]
        LIGHTS["AstroPixels Displays (FLD, RLD, PSIs, HPs)"]
        PCA["PCA9685 16-Channel Servo Driver"]
        SERVOS["6x Holoprojector Servos"]
        HALL["KY-003 Hall Homing Sensor"]
        DOME_BUCK["Dome 5V Buck Converter"]

        BATTERY -->|"Fused 12V"| CH1 --> DOME_BUCK --> ESP32
        DOME_BUCK --> RX
        BATTERY -->|"Common Ground"| CH2 --> DOME_BUCK

        RX -->|"iBUS (5V to Shifter to GPIO16)"| ESP32
        VESC -->|"Telemetry TX (Port 3 Pin 5)"| CH3 -->|"GPIO5 RX (AUX 3)"| ESP32
        ESP32 -->|"UART TX (GPIO17)"| CH4 -->|"1k Resistor"| DFPLAYER
        ESP32 -->|"LEDC PWM (GPIO4)"| CH5 --> DOME_SERVO
        ESP32 -->|"VESC UART (GPIO18 AUX 4)"| CH6 -->|"Port 3 COMM RX"| VESC
        ESP32 --> LIGHTS
        ESP32 -->|"I2C (GPIO21 / 22)"| PCA --> SERVOS
        HALL -->|"Via Level Shifter to GPIO19"| ESP32
    end
```

> [!WARNING]
> **Single Hall Sensor vs. Approved Dual Hall Architecture:**
> The diagram above reflects the **historical single-ESP32 sketch** (`ASTROPIXELS_UNIFIED_BRAIN.ino`), which only used a **single Hall sensor** on GPIO 19.
> 
> The **approved build** uses **two KY-003 Hall sensors** (Front 0° on GPIO 19 and Rear 180° on GPIO 18 via Lonely Binary dome shifter CH2/CH3) with one ring magnet. This eliminates ambiguous 180° stalls and provides verified timing and direction tracking. See [Dome Wiring Diagram](DOME_WIRING_DIAGRAM.md) and [System Architecture](SYSTEM_ARCHITECTURE.md) for the authoritative dual-sensor schematics.

---

## 2. MicroSD Card Audio Directory & Sound Pools

Format the MicroSD card as **FAT32**. Place audio files in the root folder or an `/MP3/` folder using **3-digit numerical prefixes** (e.g., `001.mp3`, `102.mp3`):

### A. Ambient Chatter Sound Pools
When R2 is idling in a persistent mood, background chatter randomly plays tracks from that mood's assigned bank:

| Track Range | Mood Category | Description & Style |
| :---: | :--- | :--- |
| `001 – 020` | **Happy & Chatty** | Upbeat whistling, harmonic chirps, friendly beeps |
| `021 – 040` | **Sassy & Annoyed** | Grumbling razzes, sarcastic buzzes, scoffing beeps |
| `041 – 060` | **Sad & Mournful** | Low downward whines, melancholic chirps |
| `061 – 080` | **Alert & Alarm** | Fast warning pulses, emergency chirps, klaxons |

---

### B. Synchronized Macro Routines
Triggered by flipping **switch `SwC` DOWN** on the transmitter:

| Track # | Routine Name | Dial `VrA` Position | Synchronized Behavior |
| :---: | :--- | :---: | :--- |
| `102` | **Scream / Panic** | **Pos 4** | Red flashing strobe + staggered, low-amplitude holoprojector twitches (4.5s) |
| `106` | **Cantina Band** | **Pos 5** | Marching lights + synchronized holoprojector dance steps (30s) |
| `109` | **Princess Leia** | **Pos 6** | Auto-aligns dome forward to 0° + pale green logics + front HP dips down 35° with blue flicker (14s) |
| `110` | **Star Wars Disco** | **Pos 7** | Full rainbow wave across all displays (20s) |
| `107` | **Short Circuit / Faint**| **Pos 8** | Brief dim flicker, all displays go dark, servo PWM disabled for 5s, then re-centers |
| `011` | **Auto-Center Reset** | **Pos 1** | Rotates dome to lock onto the magnet (0° home), centers all servos, resets lights |
| `255` | **Startup Chime** | *Boot* | Plays automatically on power-up |

---

## 3. FlySky FS-i6X Transmitter Channel Assignments

| Channel | Physical Control | Function |
| :---: | :--- | :--- |
| **CH 1** | Right Stick Horizontal | **Steering:** Differential tank steering mixed by ESP32 |
| **CH 2** | Right Stick Vertical | **Throttle:** Forward and reverse throttle mixed by ESP32 |
| **CH 3** | Left Stick Vertical | **Manual Front Holo Tilt:** Overrides servo; holds position for 3s before resuming ambient moves |
| **CH 4** | Left Stick Horizontal | **Manual Dome Rotation:** Proportional continuous speed control; stops dead at center |
| **CH 5** | Switch `SwB` (3-Pos) | **Dual Rates (Speed):** Pos 1 = Slow (35%), Pos 2 = Medium (70%), Pos 3 = Fast (100%) |
| **CH 6** | Switch `SwA` (2-Pos) | *Unused* |
| **CH 7** | Knob `VrA` | **Mood & Macro Selector:** Selects active mood (Pos 1–13) |
| **CH 8** | Switch `SwC` (3-Pos) | **Macro Trigger:** Flip DOWN to trigger the routine selected by `VrA` |
| **CH 9** | Switch `SwD` (2-Pos) | **Holoprojector Motion Toggle:** High enables random autonomous twitches; Low pauses them |

---

## 4. Software Performance & Architecture

* **Zero Dynamic Heap Allocation:** Avoids `malloc()`, `free()`, and the `String` class during the main loop to prevent heap fragmentation.
* **PROGMEM Storage:** Sound lookup tables and macro definitions are stored in Flash memory.
* **Hardware Timers & Offloading:**
  * Dome Continuous Servo PWM: Generated by the ESP32 hardware **LEDC timer** (near-zero CPU overhead).
  * iBUS & Sound: Processed via **Hardware UART1 / UART2 FIFO** buffers.
  * 6 Holoprojector Servos: Offloaded to the external **PCA9685 I2C driver**.

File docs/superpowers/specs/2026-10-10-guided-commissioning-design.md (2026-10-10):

# Guided Commissioning — Design

Date: 2026-10-10. Status: proposed.

## 1. Intent

Commissioning becomes a guided ~15-minute flow on the wireless page. The
firmware runs the tests, gathers evidence and proposes values; the operator
confirms in batches. Success: from a blank profile the operator reaches
"drive + manual dome + auto dome ready and saved" using only the web page and
the transmitter (no USB/CLI).

Constraints kept from the current design:

- Every acceptance bit still needs an explicit operator click.
- Actuators run only the saved profile; edits are staged until Save.
- Both boards are flashed together (the link protocol changes).
- Everything is covered by host tests.

Decisions taken with the operator:

| Topic | Decision |
| --- | --- |
| Wheel tests | Web page only, CH6 OFF, sticks centred, "wheels are raised" confirmation, browser keepalive (the open `/drive` page's live status poll is a heartbeat every ~150 ms; the ESP32 forwards Keepalive only while the last heartbeat is ≤500 ms old; dome tests keep the ESP32-driven keepalive), duty ≤10%, spin ≤2 s; CH6 ON / stick / keepalive loss brakes |
| Wheel sign-off evidence | Bits 6–11 require that wheel's completed automated test against the saved settings |
| CH9 | Not used by any commissioning test, Accept, SetField or Save. After a Save makes auto dome ready, auto dome waits for CH9 OFF→ON |
| Baseline | Fills unset fields only |
| Logic placement | Teensy runs tests and baseline; ESP32 sequences, mirrors and prompts |

## 2. Protocol changes (`shared/R2BodyLink/Messages.h`)

- `CommissionRequest.operation` 7 = **ApplyBaseline** (test/field/wheel/value 0).
- `CommissionRequest` Begin (op 1): `test` 1–8. Dome tests 1–5 keep
  wheel=0, value=0. Wheel tests: 6 **TimeoutBrake**, 7 **Direction**,
  8 **Reversal**, with `wheel` 0/1 and `value` = 1 ("wheels are raised";
  any other value is invalid).
- `CommissionStatus` adds: `staged_acceptance` (u16), `saved_acceptance`
  (u16), `unsaved` (u8, staged ≠ saved), and wheel results `wheel` (u8),
  `stop_ms` (u16), `peak_current_cA` (i16, 0.01 A), `peak_erpm` (i32),
  `vesc_fault` (u8). Wire size 36 → 51.
- `Diagnostics` subtype 1 (field read) adds `known` (u8): 1 when the field is set, so an unset field is not mistaken for 0. Wire size 11 → 12.
- Body publishes `VescStatus` whenever the VESC firmware has been observed;
  `valid_fields` = 0 when the sample is not valid, so the page can show
  detected firmware before commissioning.

## 3. Teensy

### 3.1 Baseline (`ConfigStore`)

`applyBaseline(profile, observed_fw)` sets only unset fields:

| Field | Baseline |
| --- | --- |
| servo_neutral / min / max | 1500 / 1000 / 2000 |
| auto_speed | 15 % |
| slew | 500 ‰/s |
| fw_major / fw_minor (per wheel) | observed VESC firmware, only if observed |
| layout | 1 |
| motor / battery / regen / brake | 12000 / 5000 / 2500 / 3000 mA |
| undervoltage / overvoltage | 1100 / 1480 cV |
| timeout_ms / timeout_brake_ma | 150 / 3000 |
| reversal_erpm / reversal_dwell | 300 / 200 ms |
| direction, cw_rate, ccw_rate | left unset (set by tests) |

Gate: stationary gate (3.2), no test running. CLI: `profile baseline`.

### 3.2 Gates (`DomeCalibration`)

Stationary gate = fresh RC, CH6 OFF, sticks (CH1/2/4) centred, no motion
lock. Used by Begin, SetField, Accept, Save and ApplyBaseline. CH9 is no
longer consulted. A running test is cancelled on CH6 ON, stick deflection,
stale RC, keepalive loss (>300 ms) or a motion lock.

### 3.3 Wheel tests (`WheelTest`, new)

Pure logic: input = wheel telemetry samples + time; output = command
{Disable, Duty(permille), Brake} for the tested wheel. The other wheel is
disabled. Constants: spin duty 100 ‰, spin-up 1000 ms, "turning" ≥ 100 eRPM
(all thresholds stay in eRPM, so no motor pole count is needed; a stopped
Hall-sensored motor reads ~0 eRPM), overall test limit 6 s.

- **TimeoutBrake**: spin 1000 ms (must reach turning speed, else Failed
  "did not turn"), then stop sending commands. Pass when |eRPM| falls below
  10% of the spin speed within 1500 ms (the VESC's own 150 ms timeout brake).
  Records stop_ms and peak |motor current| after the cut-off. Still turning at
  1500 ms → Failed "VESC timeout brake not active".
- **Direction**: spin 1500 ms at raw +100 ‰, then brake 300 ms. Pass when it
  reached turning speed. The page then asks "did this foot roll forward?";
  the answer stages `direction` ±1. Accept then needs that answer.
- **Reversal**: spin +100 ‰ for 1000 ms, then brake at the saved brake current
  until |eRPM| ≤ reversal_erpm for reversal_dwell, then −100 ‰ for 1000 ms,
  then brake. Pass when the eRPM sign reversed at turning speed and no fault.
  Records the brake-to-low-speed time and peak current.
- Any VESC fault, stale telemetry, or abort condition → brake 300 ms, then
  Failed/Cancelled with the fault code.

`VescLink` commissioning mode: while a wheel test runs, duty ≤100 ‰ and the
saved brake current are permitted once that wheel's `vesc_config` is
accepted **and saved**, its firmware matches and telemetry is fresh (timeout,
direction and reversal bits are not yet required). While commissioning mode
is on, duty above 100 ‰ is refused even for a fully control-accepted wheel.

### 3.4 Evidence

Each completed test records a digest of the saved settings it ran against:

| Bit | Test | Digest fields |
| --- | --- | --- |
| 0 | Neutral | servo trims, auto speed |
| 1 / 2 | FrontRef / RearRef | servo trims, auto speed |
| 3 | TimingCw + TimingCcw | servo trims, auto speed |
| 6/7 | TimeoutBrake (wheel) | wheel fields 6–16 |
| 8/9 | Direction (wheel) | wheel fields 6–14 (the `direction` answer is staged after the test and must be set) |
| 10/11 | Reversal (wheel) | wheel fields 6–14, 17, 18 |

Accept succeeds only when the staged values of those fields equal the
recorded digest. Dome tests keep their existing staged-config evidence
(they run on staged trims); wheel tests run on saved settings.

### 3.5 Auto-dome re-arm (`DomeController`)

`activateSavedProfile()` notifies the dome controller; when the activation
newly makes auto dome ready, auto behaviour (startup alignment, seeks, idle
velocity) stays inhibited until CH9 is observed OFF and then ON. Boot with
CH9 already ON keeps today's behaviour.

## 4. ESP32

- **`ProfileMirror`**: one Read in flight, round-robin over the 7 global and
  2×14 wheel fields while the link is up (≈3 s per full pass); caches
  value + known flag per field. Used by the field table and checklist.
- **`CommissionWizard`**: "Calibrate dome" runs FrontRef → RearRef →
  TimingCw → TimingCcw, each Begin + wait for Completed of that run id;
  stops on the first failure with its error. "Accept all & Save" sends
  Accept 1, 2, 3 then Save. Neutral is its own step with **Nudge −5 / +5 µs**
  (SetField servo_neutral, restart the 3 s hold) and **Accept neutral**.
- **Wheel flow**: "Accept VESC config & Save" (bits 4/5 + Save) after the
  operator compares VESC Tool; then per wheel **Run timeout**, **Run
  direction** (+ Forward/Backward answer), **Run reversal**; then
  "Accept wheel tests & Save" (bits 6–11 that have evidence + Save).
- **`RadioCheck`**: prompts in order, each passing when the condition is
  seen within 15 s: right stick up (CH2 > 1750), right stick right
  (CH1 > 1750), left stick right (CH4 > 1750) — the three stick prompts say
  "with SwA UP" and count only while CH6 < 1250 — SwA down (CH6 > 1750),
  SwC through 3 positions (CH5 low/mid/high), SwB down (CH8 > 1750),
  SwD down (CH9 > 1750; the prompt warns that a saved auto dome may turn),
  knob sweep (CH7 < 1100 then > 1900). Transmitter macros (SwB) do not fire
  while the check is prompting; a SwB still DOWN when it ends needs a fresh
  flip. Prompt text holds no quotes or backslashes (ReelTwo puts it into
  JavaScript strings unescaped). Failsafe:
  "turn the transmitter off" — pass when frames keep arriving with
  CH1/2/4 centred, CH6/8/9 ≤ 1250; frames stopping is reported as "no
  failsafe frames (receiver stops output)" — drive still disarms on staleness.
- **`AudioCheck`**: play track 255; pass on PlaybackStarted within 3 s.
- **Pages**: `/commissioning` = checklist, baseline, dome steps, radio and
  audio checks. `/drive` = detected VESC firmware, named field table
  (edit-in-place, staged vs saved), wheel tests and their results.
- **Checklist**: baseline filled · VESC config L/R · timeout L/R ·
  direction L/R · reversal L/R · neutral · front/rear refs · timing · radio ·
  failsafe · audio · saved (no unsaved changes). Radio/failsafe/audio are
  session results, not acceptance bits.

## 5. Testing

- Teensy unit tests: baseline fill-only and ranges; gates without CH9;
  `WheelTest` per test with scripted telemetry (pass, did-not-turn, timeout
  inactive, fault, abort on CH6/stick/keepalive); VescLink commissioning
  permission; evidence and digest mismatch; auto-dome re-arm; protocol
  validation of the new fields/ops.
- ESP32 host tests: ProfileMirror, CommissionWizard, RadioCheck, AudioCheck
  against fakes / real BodyClient over a pipe.
- Two-board integration test (success criterion): blank profile → baseline →
  VESC accept & save → wheel tests (scripted VESC that spins and responds to
  timeout) → dome wizard (scripted Hall) → accept & save → profile_ready == 7,
  using only CommissionRequests from the dome side.

## 6. Out of scope

Reading VESC configuration (mcconf) to verify limits; automatic servo-neutral
search; wiring/power checks.

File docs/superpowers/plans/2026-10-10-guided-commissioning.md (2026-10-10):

# Guided Commissioning Implementation Plan

> **For agentic workers:** REQUIRED SUB-SKILL: Use superpowers:subagent-driven-development (recommended) or superpowers:executing-plans to implement this plan task-by-task. Steps use checkbox (`- [ ]`) syntax for tracking.

**Goal:** Turn commissioning into a guided wireless flow: baseline fill, firmware auto-fill, named live fields, a dome calibration wizard, automated wheel tests (timeout-brake, direction, reversal), radio/failsafe and audio checks, and a progress checklist — with no CH9 flipping.

**Architecture:** The Teensy owns every test that moves hardware (dome tests, new `WheelTest`), the baseline, the gates and the acceptance evidence; it reports results in an extended `CommissionStatus`. The ESP32 owns operator-facing orchestration: `ProfileMirror` (field values), `CommissionWizard` (sequencing + accept/save), `RadioCheck`, `AudioCheck` and a pure `CommissionChecklist` formatter, wired into the ReelTwo web pages.

**Tech Stack:** C++11 firmware (PlatformIO: Teensy 4.1 `teensy@6.0.0`, ESP32 `espressif32 v5.2.0` + ReelTwo 23.5.3), shared `R2BodyLink` protocol library, Python `unittest` host tests compiling C++ with `c++ -std=c++11` via `tests/cpp_test_support.py:run_cpp`.

**Spec:** `docs/superpowers/specs/2026-10-10-guided-commissioning-design.md`

## Global Constraints

- Every acceptance bit still needs an explicit operator Accept; nothing auto-accepts.
- Actuators run only the saved (active) profile; edits are staged until Save.
- CH9 is not consulted by any commissioning Begin, SetField, Accept, Save or ApplyBaseline.
- Stationary gate = fresh RC (≤250 ms), CH6 < 1250 µs, CH1/CH2/CH4 within 1460–1540 µs, no motion lock.
- Wheel tests: `value` = 1 ("wheels are raised"), duty ≤ 100 ‰, spin ≤ 2 s, "turning" ≥ 100 eRPM; CH6 ON, stick deflection, stale RC, keepalive loss (>300 ms) or motion lock → brake 300 ms then stop.
- Wheel tests need that wheel's `vesc_config` accepted **and saved**, matching firmware and fresh telemetry.
- Bits 6–11 require that wheel's completed test whose digest of the saved settings equals the staged settings at Accept.
- After a Save newly makes auto dome ready, auto dome waits for CH9 OFF→ON.
- ApplyBaseline fills unset fields only, with the spec's baseline table values.
- `CommissionStatus` wire size 51; `Diagnostics` subtype 1 wire size 12.
- Run all host tests with `python3 -m unittest discover -s tests -p "test_*.py"` from the repo root; build checks with `pio run` in each firmware directory (use `PLATFORMIO_BUILD_DIR=<scratch>` to avoid touching the tree).

## Review Focus

1. A wheel test begun while that wheel is still coasting (|eRPM| ≥ 100) — expect `Inhibited`, no spin. Test in Task 6.
2. Keepalive lost mid-spin — expect brake for 300 ms, then no further commands, state `Cancelled`. Test in Task 6.
3. Save or SetField pressed while a wheel test is still braking out — expect `Busy`. Test in Task 6.
4. Baseline with no VESC firmware observed — expect firmware fields left unset, everything else filled. Test in Task 2.
5. Radio failsafe step started with switches already in their failsafe positions — must not pass without first seeing them armed. Test in Task 10.

---

## File Structure

| File | Responsibility |
| --- | --- |
| `shared/R2BodyLink/Messages.h` (modify) | New ops/tests, `CommissionStatus` fields, Diagnostics `known` |
| `TEENSY_BODY_CONTROLLER/src/body/ConfigStore.{h,cpp}` (modify) | `applyBaseline`, `fieldDigest`, `sameProfile` |
| `TEENSY_BODY_CONTROLLER/src/body/WheelTest.{h,cpp}` (create) | Pure wheel-test state machine |
| `TEENSY_BODY_CONTROLLER/src/body/VescLink.{h,cpp}` (modify) | Commissioning permission, `fw_known` |
| `TEENSY_BODY_CONTROLLER/src/body/DomeCalibration.{h,cpp}` (modify) | Gates without CH9, ApplyBaseline, wheel-test lifecycle, evidence, status fields |
| `TEENSY_BODY_CONTROLLER/src/body/DomeController.{h,cpp}` (modify) | Auto-dome re-arm after activation |
| `TEENSY_BODY_CONTROLLER/src/body/BodyController.{h,cpp}` (modify) | Wiring: samples/firmware to calibration, wheel commands to VESC links, VescStatus publish, CLI `profile baseline` |
| `ASTROPIXELS_PLUS_UNIFIED/ProfileMirror.{h,cpp}` (create) | Round-robin field reads cache |
| `ASTROPIXELS_PLUS_UNIFIED/CommissionWizard.{h,cpp}` (create) | Test sequencing, accept-and-save batches |
| `ASTROPIXELS_PLUS_UNIFIED/RadioCheck.{h,cpp}` (create) | Prompted channel + failsafe check |
| `ASTROPIXELS_PLUS_UNIFIED/AudioCheck.{h,cpp}` (create) | Startup-track playback check |
| `ASTROPIXELS_PLUS_UNIFIED/CommissionChecklist.{h,cpp}` (create) | Pure checklist formatter |
| `ASTROPIXELS_PLUS_UNIFIED/BodyClient.{h,cpp}` (modify) | Implements `IFieldReader`, `ICommissionSink` |
| `ASTROPIXELS_PLUS_UNIFIED/ASTROPIXELS_PLUS_UNIFIED.ino`, `WebPages.h` (modify) | Wiring + `/commissioning` and `/drive` pages |
| `tests/test_commissioning_*.py` (create), existing tests (modify) | Coverage |
| Guides (modify) | Commissioning workflow docs |

---

### Task 1: Protocol additions

**Files:**
- Modify: `shared/R2BodyLink/Messages.h`
- Test: `tests/test_body_link.py`

**Interfaces:**
- Produces: `CommissionRequest` op 7 (ApplyBaseline); Begin tests 6/7/8 with `wheel` 0/1 and `value` 1; `CommissionStatus` fields `uint16_t staged_acceptance, saved_acceptance; uint8_t unsaved, wheel; uint16_t stop_ms; int16_t peak_current_cA; int32_t peak_erpm; uint8_t vesc_fault;` (appended in that order after `saved`); `Diagnostics::known` (u8, subtype 1 only, appended after `value`).

- [ ] **Step 1: Write the failing tests** — append to `TypedPayloadTests` in `tests/test_body_link.py`:

```python
    def test_guided_commissioning_wire_contract(self):
        self.check(r'''
    ErrorCounters c; uint8_t buf[96]; size_t n = 0;
    CommissionRequest base = {7, 0, 0, 0, 0, 0, 3};
    assert(encodePayload(base, buf, sizeof buf, n, c) == Status::Ok);
    CommissionRequest wheel = {1, 6, 9, 0, 1, 1, 3};          // TimeoutBrake, right wheel, raised
    assert(encodePayload(wheel, buf, sizeof buf, n, c) == Status::Ok);
    wheel.test = 8; assert(encodePayload(wheel, buf, sizeof buf, n, c) == Status::Ok);
    wheel.value = 0; assert(encodePayload(wheel, buf, sizeof buf, n, c) != Status::Ok);   // not raised
    wheel.value = 1; wheel.test = 9; assert(encodePayload(wheel, buf, sizeof buf, n, c) != Status::Ok);
    CommissionRequest dome = {1, 2, 9, 0, 1, 0, 3};           // dome test with a wheel number
    assert(encodePayload(dome, buf, sizeof buf, n, c) != Status::Ok);
    CommissionStatus cs = {};
    cs.test = 8; cs.staged_acceptance = 0x0FFF; cs.saved_acceptance = 0x0010; cs.unsaved = 1;
    cs.wheel = 1; cs.stop_ms = 640; cs.peak_current_cA = -312; cs.peak_erpm = -1234; cs.vesc_fault = 3;
    assert(encodePayload(cs, buf, sizeof buf, n, c) == Status::Ok && n == 51);
    CommissionStatus back = {};
    assert(decodePayload(buf, n, back, c) == Status::Ok);
    assert(back.staged_acceptance == 0x0FFF && back.saved_acceptance == 0x0010 && back.unsaved == 1);
    assert(back.wheel == 1 && back.stop_ms == 640 && back.peak_current_cA == -312);
    assert(back.peak_erpm == -1234 && back.vesc_fault == 3);
    cs.staged_acceptance = 0x1000; assert(encodePayload(cs, buf, sizeof buf, n, c) == Status::BadReserved);
    cs.staged_acceptance = 0; cs.wheel = 2; assert(encodePayload(cs, buf, sizeof buf, n, c) == Status::BadEnum);
    Diagnostics d = {}; d.subtype = 1; d.field = 12; d.wheel = 1; d.value = 1500; d.known = 1;
    assert(encodePayload(d, buf, sizeof buf, n, c) == Status::Ok && n == 12);
    Diagnostics db = {}; assert(decodePayload(buf, n, db, c) == Status::Ok && db.known == 1 && db.value == 1500);
    d.known = 2; assert(encodePayload(d, buf, sizeof buf, n, c) == Status::BadEnum);
    Diagnostics d0 = {}; d0.known = 1; assert(encodePayload(d0, buf, sizeof buf, n, c) == Status::BadReserved);
''')
```

- [ ] **Step 2: Run to verify it fails**

Run: `cd tests && python3 -m unittest test_body_link.TypedPayloadTests.test_guided_commissioning_wire_contract`
Expected: FAIL — compile error, `no member named 'staged_acceptance'`.

- [ ] **Step 3: Implement** in `shared/R2BodyLink/Messages.h`:

Replace the `CommissionStatus` and `Diagnostics` structs:

```cpp
struct CommissionStatus {
    uint32_t run_id; uint8_t state, test; uint16_t error; uint32_t flags;
    uint16_t trial_neutral_us; uint8_t trial_speed_percent;
    uint16_t proposed_cw_ddeg_s, proposed_ccw_ddeg_s; uint32_t revolution_ms[3];
    uint32_t config_generation; uint8_t saved;
    uint16_t staged_acceptance, saved_acceptance; uint8_t unsaved;
    uint8_t wheel; uint16_t stop_ms; int16_t peak_current_cA; int32_t peak_erpm; uint8_t vesc_fault;
    static MessageType type() { return MessageType::CommissionStatus; }
};
struct Diagnostics {
    uint8_t subtype; uint32_t sample_counter;
    uint32_t counters[8];            // subtype 0 only
    uint8_t field, wheel; int32_t value;  // subtype 1 only
    uint8_t known;                   // subtype 1 only: 1 when the field is set
    static MessageType type() { return MessageType::Diagnostics; }
};
```

Wire sizes:

```cpp
inline size_t wireSize(const CommissionStatus&) { return 51; }
inline size_t wireSize(const Diagnostics& d) { return d.subtype == 0 ? 37 : 12; }
```

Replace `validate(const CommissionRequest&)`:

```cpp
inline Status validate(const CommissionRequest& m) {
    R2_CHECK(enumLE(m.operation, 7));
    R2_CHECK(enumLE(m.test, 8));
    R2_CHECK(ok01(m.wheel));
    if (m.operation == 1) {
        if (m.test == 0) return Status::BadRange;
        R2_CHECK(zero(m.field));
        if (m.test >= 6) return inRange(m.value == 1);   // wheel tests: value 1 = wheels raised
        R2_CHECK(zero(m.wheel));
        return zero(static_cast<uint32_t>(m.value));
    }
    if (m.operation == 0) {
        if (m.test != 0) return Status::BadRange;
        R2_CHECK(enumLE(m.field, 1));
        if (m.field == 0) {
            R2_CHECK(zero(m.wheel));
            return zero(static_cast<uint32_t>(m.value));
        }
        return inRange(m.value >= 0 && m.value <= 20);
    }
    R2_CHECK(zero(m.test));
    if (m.operation == 4) return inRange(m.field <= 20);
    if (m.operation == 6) {
        R2_CHECK(zero(m.field));
        R2_CHECK(zero(m.wheel));
        return inRange(m.value >= 0 && m.value <= 31);
    }
    R2_CHECK(zero(m.field));
    R2_CHECK(zero(m.wheel));
    return zero(static_cast<uint32_t>(m.value));
}
```

Replace `validate(const CommissionStatus&)` and `validate(const Diagnostics&)`:

```cpp
inline Status validate(const CommissionStatus& m) {
    R2_CHECK(enumLE(m.state, 5));
    R2_CHECK(enumLE(m.test, 8));
    R2_CHECK(ok01(m.saved));
    R2_CHECK(enumLE(m.trial_speed_percent, 100));
    R2_CHECK(maskOnly(m.staged_acceptance, 0x0FFF));
    R2_CHECK(maskOnly(m.saved_acceptance, 0x0FFF));
    R2_CHECK(ok01(m.unsaved));
    R2_CHECK(ok01(m.wheel));
    return inRange(m.trial_neutral_us == 0 || (m.trial_neutral_us >= 1400 && m.trial_neutral_us <= 1600));
}
inline Status validate(const Diagnostics& m) {
    R2_CHECK(enumLE(m.subtype, 1));
    if (m.subtype == 0) {
        R2_CHECK(zero(m.field));
        R2_CHECK(zero(m.wheel));
        R2_CHECK(zero(m.known));
        return zero(static_cast<uint32_t>(m.value));
    }
    for (int i = 0; i < 8; ++i) R2_CHECK(zero(m.counters[i]));
    R2_CHECK(ok01(m.wheel));
    R2_CHECK(ok01(m.known));
    return inRange(m.field <= 20);
}
```

Serialization — append to `put`/`get` of `CommissionStatus` after `saved`:

```cpp
// put(Writer& w, const CommissionStatus& m), after w.u8(m.saved);
    w.u16(m.staged_acceptance); w.u16(m.saved_acceptance); w.u8(m.unsaved);
    w.u8(m.wheel); w.u16(m.stop_ms); w.i16(m.peak_current_cA); w.i32(m.peak_erpm); w.u8(m.vesc_fault);
// get(Reader& r, CommissionStatus& m), after m.saved = r.u8();
    m.staged_acceptance = r.u16(); m.saved_acceptance = r.u16(); m.unsaved = r.u8();
    m.wheel = r.u8(); m.stop_ms = r.u16(); m.peak_current_cA = r.i16(); m.peak_erpm = r.i32(); m.vesc_fault = r.u8();
```

Diagnostics `put`/`get` subtype-1 branch:

```cpp
    else { w.u8(m.field); w.u8(m.wheel); w.i32(m.value); w.u8(m.known); }
// get:
    m.field = m.wheel = 0; m.value = 0; m.known = 0;
    ...
    else { m.field = r.u8(); m.wheel = r.u8(); m.value = r.i32(); m.known = r.u8(); }
```

`decodePayload` length gate: replace `length != 37 && length != 11` with `length != 37 && length != 12`.

- [ ] **Step 4: Update the existing wire-size tests that pin the old sizes** in `tests/test_body_link.py`: `RT(CommissionStatus, cs, 36)` → `51`; `RT(Diagnostics, d1, 11)` → `12` with `Diagnostics d1 = {1, 6, {0}, 3, 1, -9, 1};`; the CommissionStatus wire-order assertion's `buf[35] == 1` is unchanged; the length-validation lines `sf = makeFrame(1, 35, 0)` → `makeFrame(1, 50, 0)` and `sf.length = 37` → `52`; `cs.test = 7; BAD(...)` → `cs.test = 9`; in the decode-rejects test `uint8_t cs[36]` / `decodePayload(cs, 36, st, c)` → `51`; `decodePayload(dg, 11, d, c)` → `12`. In `test_body_integration.py` no change. Also update the request REJECT list line `request = {6, 1, 0, 0, 0, 1, 0}; REJECT(request);` stays valid (op 6 with test 1 still rejected).

- [ ] **Step 5: Run the protocol and full suites**

Run: `cd tests && python3 -m unittest test_body_link` then `cd .. && python3 -m unittest discover -s tests -p "test_*.py"`
Expected: PASS. If `BodyController.cpp`/`DomeCalibration.cpp` fail to compile because `Diagnostics`/`CommissionStatus` aggregate initializers changed, they use value-init (`{}`) and should compile; fix any positional initializer by switching it to named-field assignment.

- [ ] **Step 6: Commit**

```bash
git add shared/R2BodyLink/Messages.h tests/test_body_link.py
git commit -m "feat(link): commissioning baseline op, wheel tests, extended status, field-known flag"
```

---

### Task 2: Baseline, field digest and profile comparison (`ConfigStore`)

**Files:**
- Modify: `TEENSY_BODY_CONTROLLER/src/body/ConfigStore.h`, `ConfigStore.cpp`
- Test: create `tests/test_commissioning_baseline.py`

**Interfaces:**
- Produces:
  - `struct ObservedFirmware { bool valid; uint8_t major, minor; };`
  - `uint8_t applyBaseline(CommissioningProfile& p, const ObservedFirmware fw[2]);` — fills unset fields only, returns the number filled.
  - `uint32_t fieldDigest(const CommissioningProfile& p, uint8_t wheel, const uint8_t* ids, size_t n);` — FNV-1a over (id, set flag, value) of those fields; never 0.
  - `bool sameProfile(const CommissioningProfile& a, const CommissioningProfile& b);` — all fields' set flags and values, `acceptance` and `allow_remote_drive` equal.

- [ ] **Step 1: Write the failing test** — create `tests/test_commissioning_baseline.py`:

```python
"""Guided commissioning: baseline fill, digests and profile comparison."""
import unittest
from pathlib import Path
from cpp_test_support import run_cpp

ROOT = Path(__file__).resolve().parents[1]
BODY = ROOT / "TEENSY_BODY_CONTROLLER/src"
SHARED = ROOT / "shared/R2BodyLink"
SOURCES = [BODY / "body/ConfigStore.cpp", SHARED / "src/Codec.cpp"]
PRELUDE = r'''
#include <cassert>
#include "body/ConfigStore.h"
using namespace body;
static int32_t get(const CommissioningProfile& p, uint8_t id, uint8_t w) {
    int32_t v = -999; return getField(p, id, w, v) ? v : -999;
}
'''

class BaselineTests(unittest.TestCase):
    def check(self, body):
        result = run_cpp(PRELUDE + "int main() {\n" + body + "\nreturn 0;\n}\n",
                         extra_sources=SOURCES, include_dirs=[BODY, SHARED])
        self.assertEqual(result.returncode, 0, result.stdout + result.stderr)

    def test_baseline_fills_every_unset_field_with_the_spec_values(self):
        self.check(r'''
    CommissioningProfile p;
    const ObservedFirmware fw[2] = {{true, 6, 2}, {true, 6, 2}};
    assert(applyBaseline(p, fw) == 5 + 2 * 13);
    assert(get(p, kFieldServoNeutral, 0) == 1500 && get(p, kFieldServoMin, 0) == 1000);
    assert(get(p, kFieldServoMax, 0) == 2000 && get(p, kFieldAutoSpeed, 0) == 15 && get(p, kFieldSlew, 0) == 500);
    for (uint8_t w = 0; w < 2; ++w) {
        assert(get(p, kFieldFwMajor, w) == 6 && get(p, kFieldFwMinor, w) == 2 && get(p, kFieldLayout, w) == 1);
        assert(get(p, kFieldMotorMa, w) == 12000 && get(p, kFieldBatteryMa, w) == 5000);
        assert(get(p, kFieldRegenMa, w) == 2500 && get(p, kFieldBrakeMa, w) == 3000);
        assert(get(p, kFieldUndervoltage, w) == 1100 && get(p, kFieldOvervoltage, w) == 1480);
        assert(get(p, kFieldTimeoutMs, w) == 150 && get(p, kFieldTimeoutBrakeMa, w) == 3000);
        assert(get(p, kFieldReversalErpm, w) == 300 && get(p, kFieldReversalDwell, w) == 200);
        assert(get(p, kFieldDirection, w) == -999);   // set by the direction test
    }
    assert(get(p, kFieldCwRate, 0) == -999 && get(p, kFieldCcwRate, 0) == -999);
    assert(validateProfile(p));
''')

    def test_baseline_never_overwrites_and_skips_unknown_firmware(self):
        self.check(r'''
    CommissioningProfile p;
    assert(setField(p, kFieldBrakeMa, 1, 4200) == FieldResult::Ok);
    assert(setField(p, kFieldServoNeutral, 0, 1512) == FieldResult::Ok);
    const ObservedFirmware fw[2] = {{false, 0, 0}, {true, 5, 3}};
    applyBaseline(p, fw);
    assert(get(p, kFieldBrakeMa, 1) == 4200 && get(p, kFieldServoNeutral, 0) == 1512);
    assert(get(p, kFieldFwMajor, 0) == -999 && get(p, kFieldFwMinor, 0) == -999);
    assert(get(p, kFieldFwMajor, 1) == 5 && get(p, kFieldFwMinor, 1) == 3);
    assert(applyBaseline(p, fw) == 0);   // idempotent
''')

    def test_field_digest_and_same_profile(self):
        self.check(r'''
    CommissioningProfile a, b;
    const ObservedFirmware fw[2] = {{true, 6, 2}, {true, 6, 2}};
    applyBaseline(a, fw); b = a;
    const uint8_t ids[] = {kFieldBrakeMa, kFieldTimeoutMs};
    assert(fieldDigest(a, 0, ids, 2) == fieldDigest(b, 0, ids, 2) && fieldDigest(a, 0, ids, 2) != 0);
    assert(sameProfile(a, b));
    assert(setField(b, kFieldBrakeMa, 0, 3100) == FieldResult::Ok);
    assert(fieldDigest(a, 0, ids, 2) != fieldDigest(b, 0, ids, 2));
    assert(fieldDigest(a, 1, ids, 2) == fieldDigest(b, 1, ids, 2));   // other wheel untouched
    assert(!sameProfile(a, b));
    b = a; b.acceptance |= 1u << kAcceptVescConfig; assert(!sameProfile(a, b));
''')

if __name__ == "__main__":
    unittest.main()
```

- [ ] **Step 2: Run to verify it fails**

Run: `cd tests && python3 -m unittest test_commissioning_baseline`
Expected: FAIL — compile error, `unknown type name 'ObservedFirmware'`.

- [ ] **Step 3: Implement.** In `ConfigStore.h` after `uint8_t faultBits(ConfigResult r);` add:

```cpp
// Firmware a VESC reported over UART; valid=false when none was observed.
struct ObservedFirmware { bool valid; uint8_t major, minor; };
// Fills only unset fields with the recommended baseline (guided commissioning
// spec section 3.1); firmware fields only from observed firmware. Returns the
// number of fields filled. Never touches acceptance bits directly.
uint8_t applyBaseline(CommissioningProfile& p, const ObservedFirmware fw[2]);
// FNV-1a over (id, set flag, value) for the listed fields of one wheel; never 0.
uint32_t fieldDigest(const CommissioningProfile& p, uint8_t wheel, const uint8_t* ids, size_t n);
// True when every field (set flag and value), acceptance and allow_remote_drive match.
bool sameProfile(const CommissioningProfile& a, const CommissioningProfile& b);
```

In `ConfigStore.cpp` (outside the anonymous namespace, after `readiness`):

```cpp
uint8_t applyBaseline(CommissioningProfile& p, const ObservedFirmware fw[2]) {
    struct B { uint8_t id; int32_t value; };
    static const B kGlobal[] = {{kFieldServoNeutral, 1500}, {kFieldServoMin, 1000}, {kFieldServoMax, 2000},
                                {kFieldAutoSpeed, 15}, {kFieldSlew, 500}};
    static const B kWheel[] = {{kFieldLayout, 1}, {kFieldMotorMa, 12000}, {kFieldBatteryMa, 5000},
                               {kFieldRegenMa, 2500}, {kFieldBrakeMa, 3000}, {kFieldUndervoltage, 1100},
                               {kFieldOvervoltage, 1480}, {kFieldTimeoutMs, 150}, {kFieldTimeoutBrakeMa, 3000},
                               {kFieldReversalErpm, 300}, {kFieldReversalDwell, 200}};
    uint8_t filled = 0;
    for (const B& b : kGlobal)
        if (!isSet(p, b.id, 0) && setField(p, b.id, 0, b.value) == FieldResult::Ok) ++filled;
    for (uint8_t w = 0; w < 2; ++w) {
        for (const B& b : kWheel)
            if (!isSet(p, b.id, w) && setField(p, b.id, w, b.value) == FieldResult::Ok) ++filled;
        if (fw[w].valid) {
            if (!isSet(p, kFieldFwMajor, w) && setField(p, kFieldFwMajor, w, fw[w].major) == FieldResult::Ok) ++filled;
            if (!isSet(p, kFieldFwMinor, w) && setField(p, kFieldFwMinor, w, fw[w].minor) == FieldResult::Ok) ++filled;
        }
    }
    return filled;
}

uint32_t fieldDigest(const CommissioningProfile& p, uint8_t wheel, const uint8_t* ids, size_t n) {
    uint32_t h = 2166136261u;
    for (size_t i = 0; i < n; ++i) {
        const uint32_t v = static_cast<uint32_t>(rawGet(p, ids[i], wheel));
        const uint8_t bytes[6] = {ids[i], static_cast<uint8_t>(isSet(p, ids[i], wheel)),
                                  static_cast<uint8_t>(v), static_cast<uint8_t>(v >> 8),
                                  static_cast<uint8_t>(v >> 16), static_cast<uint8_t>(v >> 24)};
        for (uint8_t b : bytes) h = (h ^ b) * 16777619u;
    }
    return h == 0 ? 1 : h;
}

bool sameProfile(const CommissioningProfile& a, const CommissioningProfile& b) {
    if (a.acceptance != b.acceptance || a.allow_remote_drive != b.allow_remote_drive) return false;
    for (size_t i = 0; i < kSpecCount; ++i) {
        const Spec& s = kSpecs[i];
        for (uint8_t w = 0; w < (s.wheel ? 2 : 1); ++w) {
            if (isSet(a, s.id, w) != isSet(b, s.id, w)) return false;
            if (isSet(a, s.id, w) && rawGet(a, s.id, w) != rawGet(b, s.id, w)) return false;
        }
    }
    return true;
}
```

The baseline counts: 5 globals + 11 per-wheel fields + 2 firmware fields = 13 per wheel → `5 + 2*13` in the test.

- [ ] **Step 4: Run tests**

Run: `cd tests && python3 -m unittest test_commissioning_baseline test_body_link`
Expected: PASS.

- [ ] **Step 5: Commit**

```bash
git add TEENSY_BODY_CONTROLLER/src/body/ConfigStore.h TEENSY_BODY_CONTROLLER/src/body/ConfigStore.cpp tests/test_commissioning_baseline.py
git commit -m "feat(config): baseline fill, field digest and profile comparison"
```

---

### Task 3: Commissioning gates without CH9, ApplyBaseline op, status masks

**Files:**
- Modify: `TEENSY_BODY_CONTROLLER/src/body/DomeCalibration.h`, `DomeCalibration.cpp`
- Test: `tests/test_dome_calibration.py`

**Interfaces:**
- Consumes: `applyBaseline`, `sameProfile`, `ObservedFirmware` (Task 2); new `CommissionStatus` fields (Task 1).
- Produces:
  - `CommissionOp::ApplyBaseline = 7`; `CommissionTest::WheelTimeout = 6, WheelDirection = 7, WheelReversal = 8` (replaces `VescTimeout`).
  - `void DomeCalibration::setSavedProfile(const CommissioningProfile& saved);` (defaults to the staged profile).
  - `void DomeCalibration::setObservedFirmware(uint8_t wheel, bool valid, uint8_t major, uint8_t minor);`
  - `status()` now fills `staged_acceptance`, `saved_acceptance`, `unsaved` on every `tick()` and after every `handleRequest()`.

- [ ] **Step 1: Write the failing tests** — add to `DomeCalibrationTests`:

```python
    def test_dome_tests_accept_and_save_never_need_ch9(self):
        self.check(r'''
    CalibrationFixture f;
    f.rc.channels[8] = 1000; f.tick(f.now + 20);          // CH9 OFF throughout
    assert(f.cal.handleRequest(f.makeSetField(kFieldServoNeutral, 0, 1500), f.now) == Result::Accepted);
    assert(f.cal.handleRequest(f.makeSetField(kFieldServoMin, 0, 1000), f.now) == Result::Accepted);
    assert(f.cal.handleRequest(f.makeSetField(kFieldServoMax, 0, 2000), f.now) == Result::Accepted);
    assert(f.cal.handleRequest(f.makeBegin(static_cast<uint8_t>(CommissionTest::Neutral), 3), f.now) == Result::Accepted);
    f.advance(f.now + 3100);
    assert(f.cal.status().state == static_cast<uint8_t>(CommissionState::Completed));
    assert(f.cal.handleRequest(f.makeAccept(kAcceptServoNeutral), f.now) == Result::Accepted);
    f.rc.channels[8] = 2000; f.tick(f.now + 20);          // and CH9 ON is fine too
    CommissionRequest save{}; save.operation = static_cast<uint8_t>(CommissionOp::Save); save.control_epoch = 1;
    assert(f.cal.handleRequest(save, f.now) == Result::Accepted);
    // CH6 ON still closes the gate.
    f.rc.channels[5] = 2000; f.tick(f.now + 20);
    assert(f.cal.handleRequest(f.makeSetField(kFieldServoNeutral, 0, 1505), f.now) == Result::Inhibited);
''')

    def test_apply_baseline_op_and_acceptance_masks_in_status(self):
        self.check(r'''
    CalibrationFixture f;
    CommissioningProfile saved;
    f.cal.setSavedProfile(saved);
    f.cal.setObservedFirmware(0, true, 6, 2);
    f.cal.setObservedFirmware(1, false, 0, 0);
    CommissionRequest b{}; b.operation = 7; b.control_epoch = 1;
    assert(f.cal.handleRequest(b, f.now) == Result::Accepted);
    int32_t v = 0;
    assert(getField(f.profile, kFieldFwMajor, 0, v) && v == 6);
    assert(!getField(f.profile, kFieldFwMajor, 1, v));
    assert(getField(f.profile, kFieldBrakeMa, 1, v) && v == 3000);
    f.profile.acceptance = 0x011;
    f.tick(f.now + 20);
    assert(f.cal.status().staged_acceptance == 0x011 && f.cal.status().saved_acceptance == 0);
    assert(f.cal.status().unsaved == 1);
    saved = f.profile; f.tick(f.now + 20);
    assert(f.cal.status().unsaved == 0 && f.cal.status().saved_acceptance == 0x011);
    f.rc.channels[5] = 2000; f.tick(f.now + 20);
    assert(f.cal.handleRequest(b, f.now) == Result::Inhibited);   // stationary gate
    // Field reads say whether the field is set.
    assert(f.cal.diagnostics(1, kFieldBrakeMa, 1, 0).known == 1 && f.cal.diagnostics(1, kFieldBrakeMa, 1, 0).value == 3000);
    assert(f.cal.diagnostics(1, kFieldDirection, 0, 0).known == 0);
''')
```

Also change the existing `test_ch6_on_manual_or_ch9_off_cancels` (it pins the removed CH9 rule): rename it `test_ch6_on_or_manual_cancels_and_ch9_off_does_not`, keep its CH6-ON and manual-stick cancellation sections, and replace its CH9-OFF section with:

```cpp
    // CH9 OFF does not cancel a running test any more.
    assert(f.cal.handleRequest(f.makeBegin(static_cast<uint8_t>(CommissionTest::TimingCw), 3), f.now) == Result::Accepted);
    f.rc.channels[8] = 1000;
    f.advance(f.now + 200);
    assert(f.cal.active());
```

(Read the existing test first; keep its CH6/manual assertions verbatim.)

- [ ] **Step 2: Run to verify it fails**

Run: `cd tests && python3 -m unittest test_dome_calibration`
Expected: FAIL — `no member named 'setSavedProfile'`.

- [ ] **Step 3: Implement** in `DomeCalibration.h`:

```cpp
enum class CommissionOp : uint8_t {
    Read = 0, Begin = 1, Keepalive = 2, Cancel = 3, SetField = 4, Save = 5, Accept = 6, ApplyBaseline = 7
};
enum class CommissionTest : uint8_t {
    None = 0, Neutral = 1, FrontRef = 2, RearRef = 3, TimingCw = 4, TimingCcw = 5,
    WheelTimeout = 6, WheelDirection = 7, WheelReversal = 8
};
```

Public additions:

```cpp
    // Actuators run the saved profile; status() compares staged against it.
    void setSavedProfile(const CommissioningProfile& saved) { saved_ = &saved; }
    void setObservedFirmware(uint8_t wheel, bool valid, uint8_t major, uint8_t minor);
```

Private additions: `const CommissioningProfile* saved_{nullptr}; ObservedFirmware observed_fw_[2]{}; void refreshStatus();`

In `DomeCalibration.cpp`:

- `stationaryGate()` becomes `return rc_.valid && rc_.channels[5] < 1250 && isSticksNeutral() && !motion_locked_;` (RC freshness is folded into `rc_.valid` by the snapshot).
- Begin: delete the `if (test != CommissionTest::VescTimeout) { CH9 ... }` block and replace with `if (!isSticksNeutral()) return r2link::Result::Inhibited;`; change the range check `static_cast<uint8_t>(test) > 6` to `> 5` for now (wheel tests arrive in Task 6; until then Begin 6–8 returns `InvalidArgument`).
- `tick()`: replace the `if (test != CommissionTest::VescTimeout) { if (rc_.channels[8] < 1750 || !isSticksNeutral()) ... }` block with `if (!isSticksNeutral()) { cancel(now_ms); return; }`.
- Add the ApplyBaseline handler before `if (op == CommissionOp::Read)`:

```cpp
    if (op == CommissionOp::ApplyBaseline) {
        if (status_.state == static_cast<uint8_t>(CommissionState::Running)) return r2link::Result::Busy;
        if (!stationaryGate()) return r2link::Result::Inhibited;
        applyBaseline(profile_, observed_fw_);
        refreshStatus();
        return r2link::Result::Accepted;
    }
```

- Add:

```cpp
void DomeCalibration::setObservedFirmware(uint8_t wheel, bool valid, uint8_t major, uint8_t minor) {
    if (wheel > 1) return;
    observed_fw_[wheel].valid = valid;
    observed_fw_[wheel].major = major;
    observed_fw_[wheel].minor = minor;
}

void DomeCalibration::refreshStatus() {
    const CommissioningProfile& saved = saved_ ? *saved_ : profile_;
    status_.staged_acceptance = static_cast<uint16_t>(profile_.acceptance & 0x0FFFu);
    status_.saved_acceptance = static_cast<uint16_t>(saved.acceptance & 0x0FFFu);
    status_.unsaved = sameProfile(profile_, saved) ? 0 : 1;
}
```

- In `diagnostics()`, set `d.known = 1` when `getField(...)` succeeds (leave 0 otherwise):

```cpp
        if (getField(profile_, field, wheel, val)) { d.value = val; d.known = 1; }
```

- Call `refreshStatus()` at the very start of `tick()` and on every return path of `handleRequest()` (wrap: rename the current body to `handleRequestImpl` and make `handleRequest` call it then `refreshStatus()`).

- [ ] **Step 4: Run tests** — `cd tests && python3 -m unittest test_dome_calibration test_body_controller test_body_integration`. Expected: PASS. If a controller/integration test relied on CH9 gating, read it and confirm it asserts commissioning behaviour rather than auto dome before changing it.

- [ ] **Step 5: Commit**

```bash
git add TEENSY_BODY_CONTROLLER/src/body/DomeCalibration.* tests/test_dome_calibration.py
git commit -m "feat(commissioning): no CH9 gating, ApplyBaseline op, acceptance masks in status"
```

---

### Task 4: `WheelTest` state machine

**Files:**
- Create: `TEENSY_BODY_CONTROLLER/src/body/WheelTest.h`, `WheelTest.cpp`
- Test: create `tests/test_commissioning_wheel.py`

**Interfaces:**
- Consumes: `VescSample` (`VescLink.h`).
- Produces (namespace `body`):

```cpp
enum class WheelTestKind : uint8_t { TimeoutBrake = 6, Direction = 7, Reversal = 8 };
enum class WheelTestPhase : uint8_t { Idle, Running, Passed, Failed };
struct WheelTestCommand { enum Mode : uint8_t { Disable, Duty, Brake } mode; int16_t duty_permille; };
struct WheelTestResult { uint16_t stop_ms; int16_t peak_current_cA; int32_t peak_erpm; uint8_t fault; uint16_t error; };
class WheelTest {
public:
    static const int16_t kSpinPermille = 100;
    static const int32_t kTurningErpm = 100;
    static const uint32_t kSpinMs = 1000, kDirectionSpinMs = 1500, kStopLimitMs = 1500;
    static const uint32_t kBrakeHoldMs = 300, kTestLimitMs = 6000;
    // error codes reported in WheelTestResult::error / CommissionStatus::error
    static const uint16_t kErrNotTurning = 7, kErrTimeoutBrakeInactive = 8, kErrVescFault = 9,
                          kErrTelemetry = 10, kErrNoReversal = 11, kErrTimeLimit = 13;
    void begin(WheelTestKind kind, uint16_t reversal_erpm, uint16_t reversal_dwell_ms, uint32_t now_ms);
    void update(const VescSample& sample, uint32_t now_ms);  // once per loop with the tested wheel's sample
    void abort(uint32_t now_ms);                             // brake out, then Failed with error 0
    WheelTestCommand command() const;
    WheelTestPhase phase() const;
    bool busy() const;                                       // Running, including the final brake hold
    WheelTestKind kind() const;
    const WheelTestResult& result() const;
};
```

- [ ] **Step 1: Write the failing tests** — create `tests/test_commissioning_wheel.py`:

```python
"""Guided commissioning: WheelTest state machine with scripted telemetry."""
import unittest
from pathlib import Path
from cpp_test_support import run_cpp

ROOT = Path(__file__).resolve().parents[1]
BODY = ROOT / "TEENSY_BODY_CONTROLLER/src"
SHARED = ROOT / "shared/R2BodyLink"
SOURCES = [BODY / "body/WheelTest.cpp"]
PRELUDE = r'''
#include <cassert>
#include "body/WheelTest.h"
using namespace body;
// A raised wheel: follows duty with a first-order lag, decays at `decay` erpm/ms
// when braked (or when the VESC timeout brake engages 150ms after commands stop).
struct Wheel {
    double erpm = 0; int32_t fault = 0; bool timeout_brake = true; double decay = 2.0;
    uint32_t last_cmd_ms = 0; bool stale = false;
    void step(const WheelTestCommand& c, uint32_t now) {
        if (c.mode == WheelTestCommand::Duty) { erpm += (c.duty_permille * 8.0 - erpm) * 0.01; last_cmd_ms = now; }
        else if (c.mode == WheelTestCommand::Brake) { erpm -= (erpm > 0 ? 1 : -1) * decay * (std::abs(erpm) > decay); last_cmd_ms = now; }
        else if (timeout_brake && now - last_cmd_ms > 150) erpm -= (erpm > 0 ? 1 : -1) * decay * (std::abs(erpm) > decay);
        else erpm *= 0.9995;   // coast
    }
    VescSample sample(uint32_t now) const {
        VescSample s{}; s.valid = !stale; s.stale = stale; s.erpm = int32_t(erpm); s.fault = uint8_t(fault);
        s.motor_mA = int32_t(-std::abs(erpm)); s.sample_ms = now; return s;
    }
};
static WheelTestPhase run(WheelTest& t, Wheel& w, uint32_t from, uint32_t to) {
    for (uint32_t now = from; now <= to && t.busy(); ++now) { t.update(w.sample(now), now); w.step(t.command(), now); }
    return t.phase();
}
'''

class WheelTestTests(unittest.TestCase):
    def check(self, body):
        result = run_cpp(PRELUDE.replace("#include <cassert>", "#include <cassert>\n#include <cmath>\n#include <cstdlib>")
                         + "int main() {\n" + body + "\nreturn 0;\n}\n",
                         extra_sources=SOURCES, include_dirs=[BODY, SHARED])
        self.assertEqual(result.returncode, 0, result.stdout + result.stderr)

    def test_timeout_brake_passes_when_the_vesc_stops_the_wheel(self):
        self.check(r'''
    WheelTest t; Wheel w;
    t.begin(WheelTestKind::TimeoutBrake, 300, 200, 0);
    assert(t.command().mode == WheelTestCommand::Duty && t.command().duty_permille == 100);
    assert(run(t, w, 0, 6000) == WheelTestPhase::Passed);
    assert(t.result().stop_ms > 150 && t.result().stop_ms < 1500);
    assert(t.result().peak_erpm >= 100 && t.command().mode == WheelTestCommand::Disable);
''')

    def test_timeout_brake_fails_when_the_wheel_keeps_turning(self):
        self.check(r'''
    WheelTest t; Wheel w; w.timeout_brake = false;
    t.begin(WheelTestKind::TimeoutBrake, 300, 200, 0);
    assert(run(t, w, 0, 6000) == WheelTestPhase::Failed);
    assert(t.result().error == WheelTest::kErrTimeoutBrakeInactive);
''')

    def test_a_wheel_that_never_turns_fails(self):
        self.check(r'''
    WheelTest t; Wheel w; w.decay = 1e9;   // seized: erpm stays 0
    t.begin(WheelTestKind::Direction, 300, 200, 0);
    for (uint32_t now = 0; now <= 3000 && t.busy(); ++now) { t.update(VescSample{true,0,0,0,0,0,0,0,0,0,0,0,0,now,true,true,false,false,false}, now); }
    assert(t.phase() == WheelTestPhase::Failed && t.result().error == WheelTest::kErrNotTurning);
''')

    def test_direction_spins_positive_then_brakes(self):
        self.check(r'''
    WheelTest t; Wheel w;
    t.begin(WheelTestKind::Direction, 300, 200, 0);
    assert(run(t, w, 0, 6000) == WheelTestPhase::Passed);
    assert(t.result().peak_erpm >= 100);   // signed: positive for a positive raw command
''')

    def test_reversal_brakes_dwells_and_reverses(self):
        self.check(r'''
    WheelTest t; Wheel w;
    t.begin(WheelTestKind::Reversal, 300, 200, 0);
    bool saw_brake = false, saw_reverse = false;
    for (uint32_t now = 0; now <= 6000 && t.busy(); ++now) {
        t.update(w.sample(now), now);
        saw_brake |= t.command().mode == WheelTestCommand::Brake && w.erpm > 300;
        saw_reverse |= t.command().mode == WheelTestCommand::Duty && t.command().duty_permille == -100;
        if (saw_reverse) assert(std::abs(w.erpm) <= 300 || w.erpm < 0);   // never reversed at speed
        w.step(t.command(), now);
    }
    assert(t.phase() == WheelTestPhase::Passed && saw_brake && saw_reverse);
''')

    def test_fault_stale_abort_and_time_limit(self):
        self.check(r'''
    { WheelTest t; Wheel w; t.begin(WheelTestKind::TimeoutBrake, 300, 200, 0);
      run(t, w, 0, 500); w.fault = 4;
      assert(run(t, w, 501, 6000) == WheelTestPhase::Failed);
      assert(t.result().error == WheelTest::kErrVescFault && t.result().fault == 4); }
    { WheelTest t; Wheel w; t.begin(WheelTestKind::Direction, 300, 200, 0);
      run(t, w, 0, 500); w.stale = true;
      t.update(w.sample(501), 501);
      assert(t.command().mode == WheelTestCommand::Brake);          // brake out first
      assert(run(t, w, 502, 6000) == WheelTestPhase::Failed && t.result().error == WheelTest::kErrTelemetry); }
    { WheelTest t; Wheel w; t.begin(WheelTestKind::Reversal, 300, 200, 0);
      run(t, w, 0, 700); t.abort(701);
      assert(t.command().mode == WheelTestCommand::Brake && t.busy());
      assert(run(t, w, 702, 1100) == WheelTestPhase::Failed && t.result().error == 0);
      assert(t.command().mode == WheelTestCommand::Disable); }
''')

if __name__ == "__main__":
    unittest.main()
```

Note for the implementer: `VescSample` field order is `wheel, fw_major, fw_minor, valid_fields, source_age_ms, pack_cV, motor_mA, input_mA, erpm, mosfet_dC, motor_dC, duty_permille, fault, sample_ms, valid, profile_match, stale, unsupported, motor_temperature_valid` (plus `fw_known` after Task 5). In `test_a_wheel_that_never_turns_fails` replace the aggregate with explicit assignments if the order differs: `VescSample s{}; s.valid = true; s.sample_ms = now;`.

- [ ] **Step 2: Run to verify it fails**

Run: `cd tests && python3 -m unittest test_commissioning_wheel`
Expected: FAIL — `'body/WheelTest.h' file not found`.

- [ ] **Step 3: Implement** `TEENSY_BODY_CONTROLLER/src/body/WheelTest.h` (interface exactly as in **Interfaces** above, plus private members):

```cpp
private:
    enum class Step : uint8_t { Idle, SpinUp, CoastWatch, BrakeToLow, Dwell, ReverseSpin, BrakeOut, Done };
    void finish(WheelTestPhase phase, uint16_t error, uint32_t now_ms);
    WheelTestKind kind_{WheelTestKind::TimeoutBrake};
    WheelTestPhase phase_{WheelTestPhase::Idle}, final_{WheelTestPhase::Idle};
    Step step_{Step::Idle};
    WheelTestResult result_{};
    uint16_t reversal_erpm_{0}, dwell_ms_{0};
    uint32_t begin_ms_{0}, step_ms_{0}, low_since_ms_{0};
    int32_t spin_erpm_{0};
    bool low_started_{false};
```

`WheelTest.cpp`:

```cpp
#include "body/WheelTest.h"
#include <stdlib.h>

namespace body {
namespace {
int32_t mag(int32_t v) { return v < 0 ? -v : v; }
}

void WheelTest::begin(WheelTestKind kind, uint16_t reversal_erpm, uint16_t reversal_dwell_ms, uint32_t now) {
    kind_ = kind; reversal_erpm_ = reversal_erpm; dwell_ms_ = reversal_dwell_ms;
    result_ = WheelTestResult{};
    phase_ = WheelTestPhase::Running; final_ = WheelTestPhase::Running;
    step_ = Step::SpinUp; begin_ms_ = step_ms_ = now; spin_erpm_ = 0; low_started_ = false;
}

void WheelTest::finish(WheelTestPhase phase, uint16_t error, uint32_t now) {
    final_ = phase; result_.error = error;
    step_ = Step::BrakeOut; step_ms_ = now;   // always leave the wheel braked, then released
}

void WheelTest::abort(uint32_t now) {
    if (!busy() || step_ == Step::BrakeOut) return;
    finish(WheelTestPhase::Failed, 0, now);
}

void WheelTest::update(const VescSample& s, uint32_t now) {
    if (!busy()) return;
    if (step_ == Step::BrakeOut) {
        if (now - step_ms_ >= kBrakeHoldMs) { step_ = Step::Done; phase_ = final_; }
        return;
    }
    if (now - begin_ms_ >= kTestLimitMs) { finish(WheelTestPhase::Failed, kErrTimeLimit, now); return; }
    if (s.fault) { result_.fault = s.fault; finish(WheelTestPhase::Failed, kErrVescFault, now); return; }
    if (!s.valid || s.stale) { finish(WheelTestPhase::Failed, kErrTelemetry, now); return; }
    if (mag(s.erpm) > mag(result_.peak_erpm)) result_.peak_erpm = s.erpm;
    const uint32_t in_step = now - step_ms_;
    switch (step_) {
    case Step::SpinUp: {
        const uint32_t spin = kind_ == WheelTestKind::Direction ? kDirectionSpinMs : kSpinMs;
        if (mag(s.erpm) > mag(spin_erpm_)) spin_erpm_ = s.erpm;
        if (in_step < spin) return;
        if (mag(spin_erpm_) < kTurningErpm) { finish(WheelTestPhase::Failed, kErrNotTurning, now); return; }
        if (kind_ == WheelTestKind::Direction) { finish(WheelTestPhase::Passed, 0, now); return; }
        step_ = kind_ == WheelTestKind::TimeoutBrake ? Step::CoastWatch : Step::BrakeToLow;
        step_ms_ = now;
        return;
    }
    case Step::CoastWatch: {
        const int32_t current_cA = int32_t(mag(s.motor_mA) / 10);
        if (current_cA > mag(result_.peak_current_cA)) result_.peak_current_cA = int16_t(-current_cA);
        if (mag(s.erpm) * 10 <= mag(spin_erpm_)) {
            result_.stop_ms = uint16_t(in_step);
            step_ = Step::Done; phase_ = WheelTestPhase::Passed;   // already stopped: no brake needed
            return;
        }
        if (in_step >= kStopLimitMs) finish(WheelTestPhase::Failed, kErrTimeoutBrakeInactive, now);
        return;
    }
    case Step::BrakeToLow: {
        const int32_t current_cA = int32_t(mag(s.motor_mA) / 10);
        if (current_cA > mag(result_.peak_current_cA)) result_.peak_current_cA = int16_t(-current_cA);
        if (mag(s.erpm) <= reversal_erpm_) {
            result_.stop_ms = uint16_t(in_step);
            step_ = Step::Dwell; step_ms_ = now; low_since_ms_ = now;
        } else if (in_step >= kStopLimitMs) {
            finish(WheelTestPhase::Failed, kErrNoReversal, now);
        }
        return;
    }
    case Step::Dwell:
        if (mag(s.erpm) > reversal_erpm_) low_since_ms_ = now;
        if (now - low_since_ms_ >= dwell_ms_) { step_ = Step::ReverseSpin; step_ms_ = now; }
        return;
    case Step::ReverseSpin:
        if (in_step < kSpinMs) return;
        if ((spin_erpm_ > 0 ? s.erpm <= -kTurningErpm : s.erpm >= kTurningErpm))
            finish(WheelTestPhase::Passed, 0, now);
        else
            finish(WheelTestPhase::Failed, kErrNoReversal, now);
        return;
    default:
        return;
    }
}

WheelTestCommand WheelTest::command() const {
    switch (step_) {
    case Step::SpinUp: return {WheelTestCommand::Duty, kSpinPermille};
    case Step::ReverseSpin: return {WheelTestCommand::Duty, int16_t(-kSpinPermille)};
    case Step::BrakeToLow: case Step::Dwell: case Step::BrakeOut: return {WheelTestCommand::Brake, 0};
    default: return {WheelTestCommand::Disable, 0};   // Idle, CoastWatch (no commands), Done
    }
}

WheelTestPhase WheelTest::phase() const { return phase_; }
bool WheelTest::busy() const { return step_ != Step::Idle && step_ != Step::Done; }
WheelTestKind WheelTest::kind() const { return kind_; }
const WheelTestResult& WheelTest::result() const { return result_; }

}  // namespace body
```

- [ ] **Step 4: Run tests** — `cd tests && python3 -m unittest test_commissioning_wheel`. Expected: PASS. If the scripted `Wheel` model's constants make a pass/fail borderline, adjust the model (not the thresholds) so that a working timeout brake stops within ~500 ms and coasting does not.

- [ ] **Step 5: Add `WheelTest.cpp` to every test source list that compiles `DomeCalibration.cpp`** (`test_dome_calibration.py`, `test_body_controller.py`, `test_body_integration.py`, `test_body_drive.py` main-rig source list, `test_body_radio.py` if it compiles `main.cpp`) — this is needed once Task 6 includes it; do it in Task 6 Step 3 instead if no test fails now.

- [ ] **Step 6: Commit**

```bash
git add TEENSY_BODY_CONTROLLER/src/body/WheelTest.* tests/test_commissioning_wheel.py
git commit -m "feat(commissioning): WheelTest state machine for timeout-brake, direction and reversal"
```

---

### Task 5: VescLink commissioning permission and `fw_known`

**Files:**
- Modify: `TEENSY_BODY_CONTROLLER/src/body/VescLink.h`, `VescLink.cpp`
- Test: `tests/test_body_vesc.py`

**Interfaces:**
- Produces:
  - `bool VescSample::fw_known;` (true once a FW_VERSION reply was seen).
  - `void VescLink::setCommissioning(bool enabled);`
  - `bool VescLink::commissioningReady(uint32_t now) const;` — `config_accepted_ && match() && sample(now).valid && !fault`.
  - `static const int16_t VescLink::kCommissionDutyLimit = 100;`

- [ ] **Step 1: Write the failing test** — add to `VescTests`:

```python
    def test_commissioning_mode_allows_low_duty_with_only_config_accepted(self):
        self.check(r'''
    CommissioningProfile p = saved();
    p.acceptance = (1u << kAcceptVescConfig) | (1u << (kAcceptVescConfig + 1));   // config only
    assert(validateProfile(p));
    Port q; VescLink l(q, 0);
    l.setProfile(VescProfile::fromSaved(p, 0)); l.tick(0);
    feed(q, l, wire({0, 42, 19}), 1); l.tick(100); feed(q, l, wire(values()), 101);
    assert(l.sample(101).fw_known && l.commissioningReady(101));
    q.tx.clear(); l.setDuty(80); l.tick(102);
    assert(count(q.tx, 5) == 0);                         // normal mode: not control-accepted
    l.setCommissioning(true);
    l.setDuty(80); l.tick(103); assert(count(q.tx, 5) == 1);
    q.tx.clear(); l.setDuty(150); l.tick(104); assert(count(q.tx, 5) == 0);   // over the 10% limit
    l.setBrake(1500); l.tick(105); assert(count(q.tx, 7) == 1);
    l.setCommissioning(false);
    q.tx.clear(); l.tick(130); l.setDuty(80); l.tick(131); assert(count(q.tx, 5) == 0);
    // Unaccepted config: never ready.
    Port r; VescLink m(r, 0); CommissioningProfile none = saved(); none.acceptance = 0;
    m.setProfile(VescProfile::fromSaved(none, 0)); m.tick(0);
    feed(r, m, wire({0, 42, 19}), 1);
    assert(m.sample(1).fw_known && !m.commissioningReady(1));
''')
```

- [ ] **Step 2: Run to verify it fails** — `cd tests && python3 -m unittest test_body_vesc.VescTests.test_commissioning_mode_allows_low_duty_with_only_config_accepted`. Expected: FAIL — `no member named 'fw_known'`.

- [ ] **Step 3: Implement.** `VescLink.h`: add `bool fw_known;` to `VescSample` (after `motor_temperature_valid`); public `void setCommissioning(bool enabled) { commissioning_ = enabled; }`, `bool commissioningReady(uint32_t now_ms) const;`, `static const int16_t kCommissionDutyLimit = 100;`; private `bool commissioning_ = false;` (initialize in the constructor list as `commissioning_(false)` after `capture_{}`... add it at the end of the member list and initializer list).

`VescLink.cpp`:

```cpp
// sample(): after s.wheel = wheel_; ...
    s.fw_known = have_firmware_;

bool VescLink::commissioningReady(uint32_t now) const {
    const VescSample s = sample(now);
    return profile_.config_accepted_ && match() && s.valid && !s.fault;
}
bool VescLink::brakePermitted() const {
    const bool allowed = profile_.control_accepted_ || (commissioning_ && profile_.config_accepted_);
    return allowed && match() && brake_ && brake_ == profile_.brake_ma_;
}
bool VescLink::dutyPermitted(uint32_t now) const {
    const VescSample s = sample(now);
    const bool commission = commissioning_ && profile_.config_accepted_ &&
        duty_ >= -kCommissionDutyLimit && duty_ <= kCommissionDutyLimit;
    return (profile_.control_accepted_ || commission) && s.valid && !s.fault && uint32_t(now - demand_ms_) <= 20;
}
```

- [ ] **Step 4: Run** `cd tests && python3 -m unittest test_body_vesc test_body_drive`. Expected: PASS.

- [ ] **Step 5: Commit**

```bash
git add TEENSY_BODY_CONTROLLER/src/body/VescLink.* tests/test_body_vesc.py
git commit -m "feat(vesc): commissioning mode and firmware-known flag"
```

---

### Task 6: Wheel tests in the commissioning lifecycle + BodyController wiring

**Files:**
- Modify: `DomeCalibration.{h,cpp}`, `BodyController.{h,cpp}`
- Test: `tests/test_dome_calibration.py`, `tests/test_body_controller.py`

**Interfaces:**
- Consumes: `WheelTest` (Task 4), `VescLink::setCommissioning/commissioningReady`, `VescSample::fw_known` (Task 5), `fieldDigest` (Task 2).
- Produces (DomeCalibration public):
  - `void setWheelReady(uint8_t wheel, bool ready);`
  - `void updateWheelSample(const VescSample& sample, uint32_t now_ms);` (tested wheel only)
  - `bool wheelTestBusy() const;` `uint8_t wheelUnderTest() const;` `WheelTestCommand wheelCommand() const;`
  - Error code 12 = wheel not ready (config not accepted+saved, firmware mismatch or stale telemetry); 14 = wheel still turning at Begin.

- [ ] **Step 1: Write failing tests** — add to `DomeCalibrationTests` (fixture already has `makeBegin`; add a helper in the PRELUDE struct):

```cpp
    CommissionRequest makeWheelBegin(CommissionTest test, uint8_t wheel, uint32_t run_id, int32_t raised = 1) {
        CommissionRequest req = makeBegin(static_cast<uint8_t>(test), run_id, raised);
        req.wheel = wheel;
        return req;
    }
    VescSample wheelSample(int32_t erpm, uint32_t t) {
        VescSample s{}; s.valid = true; s.erpm = erpm; s.sample_ms = t; return s;
    }
```

(Add `#include "body/VescLink.h"` to the PRELUDE and `BODY / "body/WheelTest.cpp"`, `BODY / "body/VescLink.cpp"` to `SOURCES`.)

```python
    def test_wheel_test_lifecycle_and_gates(self):
        self.check(r'''
    CalibrationFixture f;
    f.rc.channels[8] = 1000; f.tick(f.now + 20);
    assert(f.cal.handleRequest(f.makeWheelBegin(CommissionTest::WheelDirection, 0, 5), f.now) == Result::NotReady);
    assert(f.cal.status().error == 12);
    f.cal.setWheelReady(0, true);
    f.cal.updateWheelSample(f.wheelSample(400, f.now), f.now);          // still coasting
    assert(f.cal.handleRequest(f.makeWheelBegin(CommissionTest::WheelDirection, 0, 5), f.now) == Result::Inhibited);
    assert(f.cal.status().error == 14);
    f.cal.updateWheelSample(f.wheelSample(0, f.now), f.now);
    assert(f.cal.handleRequest(f.makeWheelBegin(CommissionTest::WheelDirection, 0, 6, 0), f.now) == Result::InvalidArgument);
    assert(f.cal.handleRequest(f.makeWheelBegin(CommissionTest::WheelDirection, 0, 6), f.now) == Result::Accepted);
    assert(f.cal.wheelTestBusy() && f.cal.wheelUnderTest() == 0);
    assert(f.cal.wheelCommand().mode == WheelTestCommand::Duty && f.cal.wheelCommand().duty_permille == 100);
    // Keepalive lost mid-spin: brake 300ms, then nothing; state Cancelled.
    for (uint32_t t = f.now + 1; t <= f.now + 400; ++t) { f.cal.updateWheelSample(f.wheelSample(600, t), t); f.tick(t); }
    assert(f.cal.status().state != static_cast<uint8_t>(CommissionState::Running));
    assert(f.cal.wheelCommand().mode == WheelTestCommand::Brake && f.cal.wheelTestBusy());
    CommissionRequest save{}; save.operation = static_cast<uint8_t>(CommissionOp::Save); save.control_epoch = 1;
    assert(f.cal.handleRequest(save, f.now) == Result::Busy);            // still braking out
    assert(f.cal.handleRequest(f.makeSetField(kFieldBrakeMa, 0, 3000), f.now) == Result::Busy);
    for (uint32_t t = f.now + 1; t <= f.now + 400; ++t) { f.cal.updateWheelSample(f.wheelSample(0, t), t); f.tick(t); }
    assert(!f.cal.wheelTestBusy() && f.cal.wheelCommand().mode == WheelTestCommand::Disable);
''')

    def test_wheel_sign_offs_need_a_passed_test_on_the_saved_settings(self):
        self.check(r'''
    CalibrationFixture f;
    CommissioningProfile saved = saved_profile_for_tests();
    f.profile = saved; f.cal.setSavedProfile(saved);
    f.rc.channels[8] = 1000; f.tick(f.now + 20);
    f.cal.setWheelReady(1, true);
    assert(f.cal.handleRequest(f.makeAccept(kAcceptTimeoutBrake + 1), f.now) == Result::Inhibited);   // no test yet
    f.cal.updateWheelSample(f.wheelSample(0, f.now), f.now);
    assert(f.cal.handleRequest(f.makeWheelBegin(CommissionTest::WheelTimeout, 1, 9), f.now) == Result::Accepted);
    // Spin 1s at 800 erpm, then the VESC stops the wheel 300ms after commands stop.
    uint32_t cut = 0;
    for (uint32_t t = f.now + 1; t <= f.now + 3000 && f.cal.wheelTestBusy(); ++t) {
        const bool spinning = f.cal.wheelCommand().mode == WheelTestCommand::Duty;
        if (!spinning && !cut) cut = t;
        const int32_t erpm = spinning ? 800 : (t - cut < 300 ? 800 : 0);
        f.cal.updateWheelSample(f.wheelSample(erpm, t), t);
        f.tick(t);
        if (t % 100 == 0 && f.cal.active()) f.cal.handleRequest(f.makeKeepalive(9), t);
    }
    assert(f.cal.status().state == static_cast<uint8_t>(CommissionState::Completed));
    assert(f.cal.status().wheel == 1 && f.cal.status().stop_ms >= 290 && f.cal.status().stop_ms <= 400);
    assert(f.cal.handleRequest(f.makeAccept(kAcceptTimeoutBrake + 1), f.now) == Result::Accepted);
    assert(f.cal.handleRequest(f.makeAccept(kAcceptTimeoutBrake), f.now) == Result::Inhibited);       // left not tested
    // A staged change to a tested field voids the evidence.
    f.profile.acceptance &= ~(1u << (kAcceptTimeoutBrake + 1));
    assert(f.cal.handleRequest(f.makeSetField(kFieldTimeoutBrakeMa, 1, 2500), f.now) == Result::Accepted);
    assert(f.cal.handleRequest(f.makeAccept(kAcceptTimeoutBrake + 1), f.now) == Result::Inhibited);
''')
```

Add to the PRELUDE (test utility, copies `test_body_vesc.py`'s `saved()` values):

```cpp
static CommissioningProfile saved_profile_for_tests() {
    CommissioningProfile p;
    for (int w = 0; w < 2; ++w) {
        const int v[] = {1, 42, 19, 1, 1000, 1000, 0, 1500, 1050, 1500, 150, 1500, 100, 50};
        for (int id = 5; id <= 18; ++id) assert(setField(p, id, w, v[id - 5]) == FieldResult::Ok);
        p.acceptance |= 1u << (kAcceptVescConfig + w);
    }
    assert(validateProfile(p));
    return p;
}
```

And in `tests/test_body_controller.py` (uses `LockRig`, `readyDrive`, `vescFrame`):

```python
    def test_wheel_test_drives_only_the_tested_vesc_with_low_duty(self):
        self.run_lock_rig(r'''
LockRig g; g.run(10);
body::CommissioningProfile& p = g.controller.profile();
readyDrive(p);
p.acceptance &= ~((0x3u << body::kAcceptTimeoutBrake) | (0x3u << body::kAcceptDirection) | (0x3u << body::kAcceptReversal));
g.save();                                              // vesc_config only, saved
// Scripted VESC replies: firmware 6.2 and a GET_VALUES reply on demand.
auto values = [](int32_t erpm) {
    std::vector<uint8_t> v(54, 0); v[0] = 4; v[27] = 0; v[28] = 128;
    v[23] = uint8_t(erpm >> 24); v[24] = uint8_t(erpm >> 16); v[25] = uint8_t(erpm >> 8); v[26] = uint8_t(erpm);
    return vescFrame(v);
};
for (int i = 0; i < 30; ++i) {
    for (FakePort* port : {&g.left_vesc_port, &g.right_vesc_port}) {
        const auto fw = vescFrame({0, 6, 2}); const auto vals = values(0);
        port->rx_bytes.insert(port->rx_bytes.end(), fw.begin(), fw.end());
        port->rx_bytes.insert(port->rx_bytes.end(), vals.begin(), vals.end());
    }
    g.run(20);
}
assert(g.controller.leftVesc().commissioningReady(g.now));
r2link::CommissionRequest begin{}; begin.operation = 1; begin.test = 7; begin.wheel = 0; begin.value = 1;
begin.run_id = 77; begin.control_epoch = g.controller.status().control_epoch;
r2link::Frame f{}; r2link::ErrorCounters e{};
assert(r2link::encode(begin, f, e) == r2link::Status::Ok);
g.left_vesc_port.tx_bytes.clear(); g.right_vesc_port.tx_bytes.clear();
assert(g.controller.handle(f, g.now) == r2link::Result::Accepted);
g.run(50);
auto duties = [](const std::vector<uint8_t>& tx, int16_t& max_permille) {
    int n = 0; max_permille = 0;
    for (size_t i = 0; i + 9 < tx.size(); ++i)
        if (tx[i] == 2 && tx[i + 1] == 5 && tx[i + 2] == 5) {
            const int32_t v = int32_t(uint32_t(tx[i+3]) << 24 | uint32_t(tx[i+4]) << 16 | uint32_t(tx[i+5]) << 8 | tx[i+6]);
            if (v / 100 > max_permille) max_permille = int16_t(v / 100);
            ++n;
        }
    return n;
};
int16_t left_max = 0, right_max = 0;
assert(duties(g.left_vesc_port.tx_bytes, left_max) > 0 && left_max == 100);
assert(duties(g.right_vesc_port.tx_bytes, right_max) == 0);
''')
```

- [ ] **Step 2: Run to verify failure** — `cd tests && python3 -m unittest test_dome_calibration test_body_controller`. Expected: FAIL — `no member named 'setWheelReady'`.

- [ ] **Step 3: Implement `DomeCalibration`.** Header: `#include "body/WheelTest.h"` and `#include "body/VescLink.h"`; public methods from **Interfaces**; private:

```cpp
    WheelTest wheel_test_;
    uint8_t wheel_{0};
    bool wheel_ready_[2]{false, false};
    VescSample wheel_sample_{};
    uint32_t wheel_done_run_[3][2]{};      // [kind-6][wheel]
    uint32_t wheel_done_digest_[3][2]{};
    static uint32_t wheelDigest(const CommissioningProfile& p, uint8_t kind_index, uint8_t wheel);
```

`DomeCalibration.cpp` additions:

```cpp
namespace {
const uint8_t kTimeoutIds[] = {6, 7, 8, 9, 10, 11, 12, 13, 14, 15, 16};
const uint8_t kDirectionIds[] = {6, 7, 8, 9, 10, 11, 12, 13, 14};
const uint8_t kReversalIds[] = {6, 7, 8, 9, 10, 11, 12, 13, 14, 17, 18};
}

uint32_t DomeCalibration::wheelDigest(const CommissioningProfile& p, uint8_t k, uint8_t w) {
    if (k == 0) return fieldDigest(p, w, kTimeoutIds, sizeof kTimeoutIds);
    if (k == 1) return fieldDigest(p, w, kDirectionIds, sizeof kDirectionIds);
    return fieldDigest(p, w, kReversalIds, sizeof kReversalIds);
}

void DomeCalibration::setWheelReady(uint8_t wheel, bool ready) { if (wheel < 2) wheel_ready_[wheel] = ready; }
void DomeCalibration::updateWheelSample(const VescSample& s, uint32_t now_ms) {
    wheel_sample_ = s;
    if (wheel_test_.busy()) wheel_test_.update(s, now_ms);
}
bool DomeCalibration::wheelTestBusy() const { return wheel_test_.busy(); }
uint8_t DomeCalibration::wheelUnderTest() const { return wheel_; }
WheelTestCommand DomeCalibration::wheelCommand() const { return wheel_test_.command(); }
```

Begin changes (in `handleRequestImpl`, op Begin): range check `test > 8` → InvalidArgument; for tests ≥ 6, after the stationary gate:

```cpp
        if (static_cast<uint8_t>(test) >= 6) {
            if (req.value != 1 || req.wheel > 1) return r2link::Result::InvalidArgument;
            if (status_.state == static_cast<uint8_t>(CommissionState::Running) || wheel_test_.busy())
                return req.run_id == status_.run_id ? r2link::Result::Accepted : r2link::Result::Busy;
            if (!wheel_ready_[req.wheel]) { status_.error = 12; return r2link::Result::NotReady; }
            if (wheel_sample_.erpm <= -WheelTest::kTurningErpm || wheel_sample_.erpm >= WheelTest::kTurningErpm) {
                status_.error = 14; return r2link::Result::Inhibited;
            }
            const CommissioningProfile& saved = saved_ ? *saved_ : profile_;
            wheel_ = req.wheel;
            wheel_done_run_[req.test - 6][wheel_] = 0;
            status_ = r2link::CommissionStatus{};   // keep acceptance fields; refreshStatus() refills them
            status_.run_id = req.run_id; status_.test = req.test; status_.wheel = wheel_;
            status_.state = static_cast<uint8_t>(CommissionState::Running);
            status_.config_generation = store_.generation();
            keepalive_deadline_ms_ = now_ms + 300;
            wheel_test_.begin(static_cast<WheelTestKind>(req.test),
                              saved.wheel[wheel_].reversal_erpm_limit, saved.wheel[wheel_].reversal_dwell_ms, now_ms);
            return r2link::Result::Accepted;
        }
```

Busy gates: SetField, Save, Accept and ApplyBaseline also return `Busy` when `wheel_test_.busy()`.

`tick()` — before the dome-test logic, handle a wheel test:

```cpp
    if (status_.state == static_cast<uint8_t>(CommissionState::Running) && status_.test >= 6) {
        const bool abort = motion_locked_ || now_ms >= keepalive_deadline_ms_ || !rc_.valid ||
                           (now_ms - rc_.sample_ms > 250) || rc_.channels[5] >= 1250 || !isSticksNeutral();
        if (abort) {
            wheel_test_.abort(now_ms);
            status_.state = static_cast<uint8_t>(now_ms >= keepalive_deadline_ms_ ? CommissionState::TimedOut
                                                                                  : CommissionState::Cancelled);
            return;
        }
        if (!wheel_test_.busy()) {
            const WheelTestResult& r = wheel_test_.result();
            status_.stop_ms = r.stop_ms; status_.peak_current_cA = r.peak_current_cA;
            status_.peak_erpm = r.peak_erpm; status_.vesc_fault = r.fault;
            if (wheel_test_.phase() == WheelTestPhase::Passed) {
                const CommissioningProfile& saved = saved_ ? *saved_ : profile_;
                const uint8_t k = status_.test - 6;
                wheel_done_run_[k][wheel_] = status_.run_id;
                wheel_done_digest_[k][wheel_] = wheelDigest(saved, k, wheel_);
                status_.state = static_cast<uint8_t>(CommissionState::Completed);
            } else {
                status_.state = static_cast<uint8_t>(CommissionState::Failed);
                status_.error = r.error;
            }
        }
        return;
    }
```

`cancel()` also calls `wheel_test_.abort(now_ms)`. `active()` stays "state == Running".

Accept — replace the `if (bit >= 4 && bit <= 11) ev.vesc_operator_observed = true;` block:

```cpp
        if (bit == kAcceptVescConfig || bit == kAcceptVescConfig + 1) {
            ev.vesc_operator_observed = true;   // operator compared VESC Tool with the staged record
        } else if (bit >= kAcceptTimeoutBrake && bit < kAcceptBitCount) {
            const uint8_t k = static_cast<uint8_t>((bit - kAcceptTimeoutBrake) / 2);   // 0 timeout, 1 direction, 2 reversal
            const uint8_t w = bit & 1;
            ev.vesc_operator_observed = wheel_done_run_[k][w] != 0 &&
                                        wheel_done_digest_[k][w] == wheelDigest(profile_, k, w);
        }
```

`acceptBit` returns `TestEvidence` when `vesc_operator_observed` is false → mapped to `Inhibited` as today.

- [ ] **Step 4: Implement `BodyController` wiring.** In the constructor body: `calibration_.setSavedProfile(active_);`. In `tick()` replace the actuator block:

```cpp
    // 3. Actuator updates
    for (uint8_t w = 0; w < 2; ++w) {
        VescLink& link = w ? right_vesc_ : left_vesc_;
        const VescSample s = link.sample(now_ms);
        calibration_.setObservedFirmware(w, s.fw_known, s.fw_major, s.fw_minor);
        calibration_.setWheelReady(w, link.commissioningReady(now_ms));
    }
    if (calibration_.wheelTestBusy()) {
        const uint8_t w = calibration_.wheelUnderTest();
        VescLink& link = w ? right_vesc_ : left_vesc_;
        calibration_.updateWheelSample(link.sample(now_ms), now_ms);
    } else {
        calibration_.updateWheelSample((calibration_.status().wheel ? right_vesc_ : left_vesc_).sample(now_ms), now_ms);
    }
    calibration_.tick(now_ms);
    if (calibration_.wheelTestBusy()) {
        const uint8_t w = calibration_.wheelUnderTest();
        VescLink& tested = w ? right_vesc_ : left_vesc_;
        VescLink& other = w ? left_vesc_ : right_vesc_;
        tested.setCommissioning(true);
        const WheelTestCommand c = calibration_.wheelCommand();
        if (c.mode == WheelTestCommand::Duty) tested.setDuty(c.duty_permille);
        else if (c.mode == WheelTestCommand::Brake) tested.setBrake(active_.wheel[w].brake_ma);
        else tested.disableControl();
        other.disableControl();
    } else {
        left_vesc_.setCommissioning(false);
        right_vesc_.setCommissioning(false);
        if (!calibration_.active()) {
            drive_.update(rc_snapshot_, left_vesc_.sample(now_ms), right_vesc_.sample(now_ms), active_, now_ms);
            applyWheelCommands(drive_.commands(), left_vesc_, right_vesc_);
        } else {
            WheelCommands neut{};
            applyWheelCommands(neut, left_vesc_, right_vesc_);
        }
    }
```

Note: the "Begin requires a stationary wheel" check reads `wheel_sample_`, which only tracks the last-tested wheel. Before Begin, `handleCommissionRequest` must feed the requested wheel: in `BodyController::handleCommissionRequest`, before `calibration_.handleRequest(req, now_ms)`, add `if (req.operation == 1 && req.test >= 6 && req.wheel < 2) calibration_.updateWheelSample((req.wheel ? right_vesc_ : left_vesc_).sample(now_ms), now_ms);`.

VescStatus publishing in `publishPeriodic()`: change `if (sl.valid) {` to `if (sl.fw_known) {` and set `vs.valid_fields = sl.valid ? sl.valid_fields : 0;` (keep the other fields; they are zeros when invalid).

CLI: add before `snprintf(out, out_max, "ERROR unknown command\n")`:

```cpp
    if (std::strcmp(line, "profile baseline") == 0) {
        r2link::CommissionRequest req{};
        req.operation = static_cast<uint8_t>(CommissionOp::ApplyBaseline);
        req.control_epoch = control_epoch_;
        const r2link::Result res = calibration_.handleRequest(req, now_ms);
        snprintf(out, out_max, res == r2link::Result::Accepted ? "OK baseline staged (profile save to apply)\n"
                                                               : "ERROR baseline refused code=%u\n", static_cast<unsigned>(res));
        return true;
    }
```

Add `BODY / "body/WheelTest.cpp"` to the SOURCES lists of `test_body_controller.py`, `test_body_integration.py`, and the main-rig source lists in `test_body_drive.py` / `test_body_radio.py` (any list that already contains `DomeCalibration.cpp`), and to `TEENSY_BODY_CONTROLLER` nothing (PlatformIO compiles `src/body/*` automatically).

- [ ] **Step 5: Run** `python3 -m unittest discover -s tests -p "test_*.py"` from the repo root. Expected: PASS.

- [ ] **Step 6: Build check** `cd TEENSY_BODY_CONTROLLER && PLATFORMIO_BUILD_DIR=/tmp/teensy_wheel pio run`. Expected: SUCCESS.

- [ ] **Step 7: Commit**

```bash
git add TEENSY_BODY_CONTROLLER/src/body tests
git commit -m "feat(commissioning): automated wheel tests with saved-settings evidence"
```

---

### Task 7: Auto-dome re-arm after a Save

**Files:**
- Modify: `DomeController.{h,cpp}`, `BodyController.cpp`
- Test: `tests/test_body_dome.py`, `tests/test_body_controller.py`

**Interfaces:**
- Produces: `void DomeController::profileActivated(bool auto_was_ready);` — when the active profile is now auto-ready and was not, auto behaviour waits for CH9 OFF→ON.

- [ ] **Step 1: Failing test** in `test_body_dome.py`:

```python
    def test_save_that_enables_auto_dome_waits_for_a_ch9_flip(self):
        self.check(r'''
DomeFixture f;
f.profile.acceptance = 1u << kAcceptServoNeutral;        // auto dome not ready yet
f.rc(0, 1500, 2000, 1000); f.setHall(0x00, 0); f.tick(20);
f.acceptAutoDome();                                       // the Save made it ready...
f.dome.profileActivated(false);
for (uint32_t t = 40; t <= 400; t += 20) { f.deliverHall(t); f.tick(t); }
assert(f.dome.state() != r2link::DomeState::SeekingReference);   // ...but CH9 was already ON
f.rc(420, 1500, 1000, 1000); f.tick(420);                       // CH9 OFF
f.rc(440, 1500, 2000, 1000); f.deliverHall(440); f.tick(440);   // CH9 ON again
f.deliverHall(460); f.tick(460);
assert(f.dome.state() == r2link::DomeState::SeekingReference);  // startup alignment now runs
''')
```

- [ ] **Step 2: Run** — `cd tests && python3 -m unittest test_body_dome`. Expected: FAIL — `no member named 'profileActivated'`.

- [ ] **Step 3: Implement.** `DomeController.h`: public `void profileActivated(bool auto_was_ready);`; private `bool auto_rearm_ = false;` (add to constructor initializer list as `auto_rearm_(false)`).

`DomeController.cpp`:

```cpp
void DomeController::profileActivated(bool auto_was_ready) {
    if (!auto_was_ready && profile_ && readiness(*profile_).auto_dome) auto_rearm_ = true;
}
```

In `tick()`, replace the first line computing `auto_dome_on`:

```cpp
    const bool ch9_on = isRcFresh(now_ms) && rc_.channels[kAutoDome] >= 1750;
    if (isRcFresh(now_ms) && rc_.channels[kAutoDome] < 1250) auto_rearm_ = false;
    const bool auto_dome_on = ch9_on && !auto_rearm_;
```

In `request()`, after the CH9 check add: `if (auto_rearm_) return r2link::Result::Inhibited;`.

`BodyController::activateSavedProfile()`:

```cpp
void BodyController::activateSavedProfile() {
    const bool auto_was_ready = readiness(active_).auto_dome;
    active_ = profile_;
    left_vesc_.setProfile(VescProfile::fromSaved(active_, 0));
    right_vesc_.setProfile(VescProfile::fromSaved(active_, 1));
    dome_.profileActivated(auto_was_ready);
}
```

(`init()` calls `activateSavedProfile()` with `active_` blank, so a boot with an auto-ready saved profile would set `auto_rearm_`; boot must keep today's behaviour — in `init()` call `dome_.profileActivated(true)` semantics by passing a flag: add a parameter `void activateSavedProfile(bool from_boot = false);` and call `dome_.profileActivated(from_boot || auto_was_ready);`; `init()` passes `true`.)

- [ ] **Step 4: Run** full suite. Expected: PASS.

- [ ] **Step 5: Commit** `git commit -am "feat(dome): auto dome waits for a CH9 flip after a Save enables it"`

---

### Task 8: ESP32 `ProfileMirror` and BodyClient interfaces

**Files:**
- Create: `ASTROPIXELS_PLUS_UNIFIED/ProfileMirror.h`, `ProfileMirror.cpp`
- Modify: `ASTROPIXELS_PLUS_UNIFIED/BodyClient.h`, `BodyClient.cpp`
- Test: create `tests/test_commissioning_dome.py`

**Interfaces:**
- Produces:

```cpp
// ProfileMirror.h
class IFieldReader {
public:
    virtual ~IFieldReader() = default;
    virtual bool requestRead(uint8_t field, uint8_t wheel, uint32_t now_ms) = 0;
};
class ICommissionSink {
public:
    virtual ~ICommissionSink() = default;
    virtual bool sendCommission(const r2link::CommissionRequest& req, uint32_t now_ms, uint16_t& seq) = 0;
};
class ProfileMirror {
public:
    static const uint8_t kSlots = 35;           // 7 global + 2 x 14 wheel fields
    static const uint32_t kReadTimeoutMs = 250, kReadSpacingMs = 50;
    explicit ProfileMirror(IFieldReader& reader);
    void tick(uint32_t now_ms, bool link_up, const r2link::Diagnostics& latest, uint32_t latest_rx_ms);
    bool value(uint8_t field, uint8_t wheel, int32_t& out) const;   // false: unknown or unset
    bool known(uint8_t field, uint8_t wheel) const;                 // a read reply arrived
    void invalidate(uint8_t field, uint8_t wheel);                  // re-read this one next
};
```

- `BodyClient` implements both: `class BodyClient : public IDomeRequestSink, public IFieldReader, public ICommissionSink`; `DiagnosticsSnapshot` gains `uint32_t rx_ms`.

- [ ] **Step 1: Failing test** — create `tests/test_commissioning_dome.py`:

```python
"""Guided commissioning: dome-side mirror, wizard, radio/audio checks, checklist."""
import unittest
from pathlib import Path
from cpp_test_support import run_cpp

ROOT = Path(__file__).resolve().parents[1]
ASTRO = ROOT / "ASTROPIXELS_PLUS_UNIFIED"
SHARED = ROOT / "shared/R2BodyLink"
PRELUDE = r'''
#include <cassert>
#include <vector>
#include "Messages.h"
#include "ProfileMirror.h"
struct Reader : IFieldReader {
    std::vector<std::pair<uint8_t, uint8_t>> asked; bool ok = true;
    bool requestRead(uint8_t f, uint8_t w, uint32_t) override { if (ok) asked.push_back({f, w}); return ok; }
};
static r2link::Diagnostics reply(uint8_t f, uint8_t w, int32_t v, uint8_t known = 1) {
    r2link::Diagnostics d{}; d.subtype = 1; d.field = f; d.wheel = w; d.value = v; d.known = known; return d;
}
'''

class DomeCommissioningTests(unittest.TestCase):
    def check(self, body, sources=()):
        result = run_cpp(PRELUDE + "int main() {\n" + body + "\nreturn 0;\n}\n",
                         extra_sources=[ASTRO / "ProfileMirror.cpp"] + list(sources), include_dirs=[ASTRO, SHARED])
        self.assertEqual(result.returncode, 0, result.stdout + result.stderr)

    def test_mirror_reads_every_field_once_per_pass_and_caches_replies(self):
        self.check(r'''
    Reader r; ProfileMirror m(r);
    r2link::Diagnostics none{}; uint32_t now = 1000;
    m.tick(now, true, none, 0);
    assert(r.asked.size() == 1 && r.asked[0].first == 0 && r.asked[0].second == 0);   // servo_neutral first
    m.tick(now + 10, true, reply(0, 0, 1512), now + 10);                             // reply arrives
    int32_t v = 0; assert(m.value(0, 0, v) && v == 1512);
    for (uint32_t t = now + 60; t < now + 60 + 35 * 60; t += 60) {
        const auto& last = r.asked.back();
        m.tick(t, true, reply(last.first, last.second, 7, last.first == 5 ? 0 : 1), t);
    }
    assert(r.asked.size() >= 35);
    assert(!m.value(5, 1, v) && m.known(5, 1));                                       // direction unset
    assert(m.value(18, 1, v) && v == 7);
''')

    def test_mirror_times_out_pauses_without_link_and_rereads_invalidated(self):
        self.check(r'''
    Reader r; ProfileMirror m(r); r2link::Diagnostics none{};
    m.tick(1000, false, none, 0); assert(r.asked.empty());
    m.tick(1000, true, none, 0); assert(r.asked.size() == 1);
    m.tick(1100, true, none, 0); assert(r.asked.size() == 1);           // waiting for reply
    m.tick(1300, true, none, 0); assert(r.asked.size() == 2);           // 250ms timeout, moved on
    m.invalidate(12, 1);
    m.tick(1600, true, none, 0);
    assert(r.asked.back().first == 12 && r.asked.back().second == 1);
''')

if __name__ == "__main__":
    unittest.main()
```

- [ ] **Step 2: Run** `cd tests && python3 -m unittest test_commissioning_dome`. Expected: FAIL — `'ProfileMirror.h' file not found`.

- [ ] **Step 3: Implement** `ProfileMirror.h` (interfaces above; `#include <cstdint>`, `"Messages.h"`), private:

```cpp
private:
    struct Slot { uint8_t field, wheel; bool known, set; int32_t value; };
    int find(uint8_t field, uint8_t wheel) const;
    IFieldReader& reader_;
    Slot slots_[kSlots];
    uint8_t next_{0};
    int outstanding_{-1};
    int priority_{-1};
    uint32_t sent_ms_{0};
```

`ProfileMirror.cpp`:

```cpp
#include "ProfileMirror.h"

ProfileMirror::ProfileMirror(IFieldReader& reader) : reader_(reader), slots_{} {
    static const uint8_t kGlobal[] = {0, 1, 2, 3, 4, 19, 20};
    uint8_t i = 0;
    for (uint8_t f : kGlobal) slots_[i++] = Slot{f, 0, false, false, 0};
    for (uint8_t w = 0; w < 2; ++w)
        for (uint8_t f = 5; f <= 18; ++f) slots_[i++] = Slot{f, w, false, false, 0};
}

int ProfileMirror::find(uint8_t field, uint8_t wheel) const {
    for (uint8_t i = 0; i < kSlots; ++i)
        if (slots_[i].field == field && slots_[i].wheel == wheel) return i;
    return -1;
}

void ProfileMirror::tick(uint32_t now, bool link_up, const r2link::Diagnostics& d, uint32_t rx_ms) {
    if (!link_up) { outstanding_ = -1; return; }
    if (outstanding_ >= 0) {
        Slot& s = slots_[outstanding_];
        if (d.subtype == 1 && d.field == s.field && d.wheel == s.wheel && rx_ms >= sent_ms_ && rx_ms != 0) {
            s.known = true; s.set = d.known != 0; s.value = d.value;
            outstanding_ = -1;
        } else if (now - sent_ms_ >= kReadTimeoutMs) {
            outstanding_ = -1;
        } else {
            return;
        }
    }
    if (now - sent_ms_ < kReadSpacingMs && sent_ms_ != 0) return;
    const int slot = priority_ >= 0 ? priority_ : next_;
    if (!reader_.requestRead(slots_[slot].field, slots_[slot].wheel, now)) return;
    outstanding_ = slot; sent_ms_ = now;
    if (priority_ >= 0) priority_ = -1;
    else next_ = static_cast<uint8_t>((next_ + 1) % kSlots);
}

bool ProfileMirror::value(uint8_t field, uint8_t wheel, int32_t& out) const {
    const int i = find(field, wheel);
    if (i < 0 || !slots_[i].known || !slots_[i].set) return false;
    out = slots_[i].value; return true;
}
bool ProfileMirror::known(uint8_t field, uint8_t wheel) const {
    const int i = find(field, wheel); return i >= 0 && slots_[i].known;
}
void ProfileMirror::invalidate(uint8_t field, uint8_t wheel) {
    const int i = find(field, wheel);
    if (i >= 0) { slots_[i].known = false; priority_ = i; }
}
```

In the first test the first `tick` at 1000 sends slot 0 with `sent_ms_ = 1000`; the reply tick at 1010 caches it; the spacing rule then waits until 1050. Adjust the test's loop start (`now + 60`) if needed so each tick both receives and sends.

- [ ] **Step 4: `BodyClient`.** `BodyClient.h`: `#include "ProfileMirror.h"`; class line `class BodyClient : public IDomeRequestSink, public IFieldReader, public ICommissionSink {`; add `uint32_t rx_ms{0};` to `DiagnosticsSnapshot`; declare `bool requestRead(uint8_t field, uint8_t wheel, uint32_t now_ms) override;` and `bool sendCommission(const r2link::CommissionRequest& req, uint32_t now_ms, uint16_t& seq) override;`.

`BodyClient.cpp`:

```cpp
bool BodyClient::requestRead(uint8_t field, uint8_t wheel, uint32_t now_ms) {
    r2link::CommissionRequest req{};
    req.operation = 0; req.field = 1; req.wheel = wheel; req.value = field;
    req.control_epoch = bodyStatus(now_ms).value.control_epoch;
    return requestCommission(req, now_ms).queued;
}
bool BodyClient::sendCommission(const r2link::CommissionRequest& req, uint32_t now_ms, uint16_t& seq) {
    const RequestHandle h = requestCommission(req, now_ms);
    seq = h.sequence;
    return h.queued;
}
// diagnostics(): set res.rx_ms = diagnostics_rx_ms_;
```

Add `ASTRO / "ProfileMirror.cpp"` to every test SOURCES list that compiles `BodyClient.cpp` (`test_body_integration.py`, `test_plus_behavior.py`'s MarcSound test).

- [ ] **Step 5: Run** the full suite. Expected: PASS.

- [ ] **Step 6: Commit** `git add ASTROPIXELS_PLUS_UNIFIED tests && git commit -m "feat(dome): profile mirror and commissioning sink interfaces"`

---
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

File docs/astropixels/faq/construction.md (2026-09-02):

> For the complete documentation index, see [llms.txt](https://r2djp.gitbook.io/astropixels/llms.txt). Markdown versions of documentation pages are available by appending `.md` to page URLs; this page is available as [Markdown](https://r2djp.gitbook.io/astropixels/faq/construction.md).

# Construction/Design

### Why JLCPCB?

Quite simply, they’re the cheapest I’ve found. And as an added bonus they have their own EasyEDA web based software with an easy path to export into their PCB manufacturing side. Plus they’re coupled with LCSC who are their component supplier. This means its a one stop shop and extremely easy to go from design to production.

### Why do you use the cable lengths you do?

These are common sizes that I can easily buy in bulk. The lengths are designed for a standard dome with the control board mounted on the back of the RLD. I looked at the various lengths and came up with the most efficient use of the standard ones available. This is why some use extension leads. Getting batches of custom made lengths would probably drive up the cost of the Astropixels quite a bit.

### Are the files available for me to make my own?

At the moment, no. But then they are generally just strings of ws2812 LEDs so not the hardest thing to replicate. Also the benefit is in the bulk purchasing. If you were to get a single set manufactured it would easily be about £200. Of course you may want to hand solder them, but if you can do that you can also design the boards.

### Why the ESP32?

I’ve been messing with Arduinos for over a decade now, and in the last few years I’ve switched to mainly ESP32 boards because the WiFi on them makes IoT devices easy to make, plus they have a lot more processing power. The development boards I use are very easy to find (must be 30pin versions for the Astropixels) and I use them in all sorts of projects.

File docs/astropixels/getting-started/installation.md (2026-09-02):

> For the complete documentation index, see [llms.txt](https://r2djp.gitbook.io/astropixels/llms.txt). Markdown versions of documentation pages are available by appending `.md` to page URLs; this page is available as [Markdown](https://r2djp.gitbook.io/astropixels/getting-started/installation.md).

# Installation

The Astropixel kit is designed to fit into the same surrounds as the old teecees lights with the same mounting holes.

## Main Board

The main breakout board can be mounted on the back of the RLD with long enough screws and some spacers. This is probably the best/easiest mounting option and the cables supplied are designed around it being in this position

## Bezels

Here is a pdf to be used with a cnc or laser cutter to make some acrylic bezels and front covers for the logics

[Bezel PDF](https://r2djp.co.uk/wp-content/uploads/2022/06/Logic-bezels-2022-astropixels.pdf)

Joel Joannisse has also done some fantastic printable bezels that can be done with some clear petg (or others).

[Printable Bezels](https://github.com/dpoulson/Astropixels/blob/main/docs/assets/Astropixels_logic_display_bezel_with_diffuser.zip)

Here is what Joel says:

```
Here are the Astropixels logic display with diffuser I been working on. It is for the 
MK4 dome. The difference here is that you screw the Astropixels board to the locking 
bar (using M3 6mm screws) of the Rear logic display instead of the RLD board it self. 

It's a multicolor print but its a single filament swap after the first layer. I use 
PETG (Transparent for the first layer, dark blue or black for the rest). You will need 
 use a 0.4 nozzle and print at 0.2 layer height. I print mine a bit hotter (265c) and 
 print the first layer at 30mm/s. I included my Bambu Studio file with those settings. 

IMPORTANT. The bezel fits really snug over the LEDs but you could apply pressure on 
them if your screws are too tight. Turn your screw just tight enough so that nothing 
moves and you are good. 
```

## Spacers

Here are a collection of STL files to 3d print for spacing the boards out from the surrounds and clear front cover. Along with 3d printable bezels.

[3d Printed Spacers](https://r2djp.co.uk/wp-content/uploads/2022/06/Logic.zip)

## HP Board mounts

Dana Jan has kindly done a dedicated HP light board mount for printed droids MK4 dome. You can find their updated files here:

[HP Board Mounts](https://www.printables.com/model/869432-holoprojector-servo-and-astropixels-mount-mk4-dome)

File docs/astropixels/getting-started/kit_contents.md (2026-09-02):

> For the complete documentation index, see [llms.txt](https://r2djp.gitbook.io/astropixels/llms.txt). Markdown versions of documentation pages are available by appending `.md` to page URLs; this page is available as [Markdown](https://r2djp.gitbook.io/astropixels/getting-started/kit_contents.md).

# Kit Contents

Your kit should contain the following:

* 1 x Main Board - This is a breakout board that everything connects to and contains the ESP32 'brain'
* 1 x Rear Logic Display (RLD)
* 2 x Front Logic Display (FLD)
* 2 x Process State Indicator (PSI)
* 3 x HoloProjectors (HP)
* 4 x 30cm Servo Extensions
* 2 x 30cm Servo cables
* 2 x 20cm Servo cables
* 4 x 10cm Servo cables

<figure><figcaption></figcaption></figure>

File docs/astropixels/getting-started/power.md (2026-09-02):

> For the complete documentation index, see [llms.txt](https://r2djp.gitbook.io/astropixels/llms.txt). Markdown versions of documentation pages are available by appending `.md` to page URLs; this page is available as [Markdown](https://r2djp.gitbook.io/astropixels/getting-started/power.md).

# Power

The Astropixels require a clean 5V supply that can provide at least 1A of current. If you change the brightness or trigger certain effects then the current usage can be quite a bit higher. Most users shouldn't go over about 700mA with normal operation.

## Options
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

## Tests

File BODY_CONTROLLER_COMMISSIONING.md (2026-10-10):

# Body and Dome Commissioning

> **Safety Notice:** Do not connect this wiring to the old ESP32-only firmware. Flash both the Teensy 4.1 body controller and the AstroPixels Plus ESP32 with the current firmware before combined testing; nothing counts as bench-verified until the commissioning record is filled in.

The Teensy body firmware, ESP32 body link client, and `/commissioning` Web UI are implemented and covered by host unit and two-board integration tests. Hardware behaviour is verified only by the checks in this guide.

**Wireless assembled-test workflow:** No laptop or USB cable is required while the dome is attached or rotating. The onboard Wi-Fi **Commissioning** page (`http://192.168.4.1/commissioning`) displays live radio/body diagnostics, both Hall sensors (Front and Rear), live test progress, revolution counts, and rotation rates. It provides guarded tests (`Neutral`, `Front Ref`, `Rear Ref`, `Timing CW`, `Timing CCW`), emergency `Cancel Test`, explicit acceptance buttons, and `Save Profile` to Teensy EEPROM. All actuator outputs remain inert and neutral until an approved commissioning profile is explicitly saved. USB instructions below apply to initial flashing or stationary setup; use the wireless page instead for installed diagnostics and rotation tests. Disconnect external programming cables before any dome rotation.

Use a multimeter, USB diagnostics, VESC Tool and the FlySky display. **No oscilloscope or logic analyzer** is required. Work in an open area with a reachable master cutoff, wheels on a secure stand and dome drive disengaged until its individual tests pass.

## 1. Carrier continuity and isolated rails

Disconnect battery, charger and USB. Remove fuses and unplug loads.

1. Confirm Treedix terminal labels by probing each terminal against its Teensy socket contact.
2. Check no continuity between the body/dome 5V positive buses. Grounds must have continuity through CH2.
3. Confirm all six ring contacts individually and no shorts between contacts; label CH4/5 spare and insulate both ends.
4. Check each inline fuse lies between its distribution takeoff and load. Removing it must break that positive feed. Verify no fan-out jumper bypasses it.
5. Fit main 25A, F3/F4 7.5A only; leave all four output fuses removed. Power the converters and measure each output: **4.9-5.1V**, correct polarity.
6. Switch off and disconnect before connecting loads. Fit B-LOGIC 2A/D-LOGIC3A first; servo fuses remain out.

Always use resistance/continuity mode with power disconnected. Capacitors can give a brief charging indication; a persistent low-resistance supply short must be investigated before applying power.

## 2. Bare Teensy USB flash

For the first flash, leave Teensy out of the carrier. Before cutting its VUSB/VIN link, USB can power the bare board without energizing any peripherals.

To build and flash the Teensy body controller:

```sh
pio run -d TEENSY_BODY_CONTROLLER -e teensy41
pio run -d TEENSY_BODY_CONTROLLER -e teensy41 -t upload
pio device monitor -d TEENSY_BODY_CONTROLLER -e teensy41 --baud 115200
```

Expect an uncommissioned state with motion disabled. Use Teensy's **Program** button if the loader requests it; it is not a general reset button. Do not enable a profile until the required physical tests are recorded.

### VUSB/VIN isolation

The approved modification separates USB5V from external VIN. It is **not** galvanic isolation; USB and droid ground still connect.

Use the **Teensy 4.1** underside card below. In the small **USB Device** detail at the lower right, PJRC's arrow says **"Cut to separate VIN from VUSB, if using external power."** It points to the short link between the two adjacent pads near the USB end. This is the cut location, not the USB-host pad group and not the Ethernet pads.

PJRC Teensy 4.1 underside reference: designated VIN/VUSB cut beside the USB Device detail

[Open the full-size official card](https://www.pjrc.com/store/teensy41_card11b_rev4.png) or use the printed card supplied with Teensy. [PJRC's Teensy 4.1 power instructions](https://www.pjrc.com/store/teensy41.html) specify separating these pads before combining USB and external VIN. Do not use underside pictures of Teensy 2.0/3.x to locate this cut.

1. Unplug USB and all power. Remove Teensy from the carrier.
2. Identify the two pads using the card's USB Device callout. Check VIN and VUSB are connected before cutting.
3. With a sharp hobby knife, cut **only the short surface copper link between those pads**. Use light passes; do not gouge into the multilayer board or cut adjacent tracks.
4. Measure between VIN and VUSB in both probe directions. There must be no direct low-resistance connection or continuous continuity tone. If still connected, inspect the cut; do not apply both power sources.
5. Check the empty Treedix carrier has no jumper/path joining VIN to VUSB. Reinstall Teensy and repeat the isolation check with all cables disconnected.
6. Supply body fused 5V to VIN and ground. Plug in a normal data USB cable and confirm diagnostics work. **USB alone will not power Teensy** after the cut.

Afterwards leave Teensy in its carrier for programming. External body power must be ON for uploads; CH6 OFF, wheels elevated and dome motion inhibited. Do not bridge the cut pads for routine programming.

If your physical board does not match the card's cut location, stop and obtain a matching photo before cutting. This is a visual-identification check, not a requirement to buy electronic test equipment.

### ESP32 USB flash

Remove ESP32 from AstroPixels with all power off. Flash the bare module from USB, then unplug USB before reinstalling. The Teensy modification does **not** isolate ESP32 USB power.

```sh
pio run -d ASTROPIXELS_PLUS_UNIFIED -e astropixelsplus
pio run -d ASTROPIXELS_PLUS_UNIFIED -e astropixelsplus -t upload
```

Do not connect mounted, externally powered ESP32 to ordinary USB. Installed updates use the acknowledged maintenance/OTA procedure below.

## 3. Body boot and Logic-shifter communication check

Keep F1 VESC and both servo output fuses out. Power body electronics through B-LOGIC 2A.

1. Confirm receiver binds and Teensy stays DISARMED/uncommissioned.
2. Check body Lonely Binary LV at 3.3V and HV at 5V against ground with the multimeter.
3. In USB diagnostics, move each stick/switch and confirm channels update, centered values are near1500us, and valid-frame counters increase.
4. Observe CH6/SwA OFF and ON explicitly. Intermediate values disarm.
5. After VESC setup supplies feedback, confirm receiver SENSOR polls and voltage/temperature responses; compare external voltage to pack voltage, not receiver5V. Run input and telemetry together.
6. Stale telemetry must appear unavailable; it must not become a zero or frozen "fresh" reading. Confirm how the handheld indicates sensor loss.

Troubleshooting: disable motion, disconnect power, check continuity/channel pairing and solder joints, check supply rails powered, test SERVO and SENSOR separately on short leads, then swap in a spare Lonely Binary board and repeat the combined test. Do not change translators or buy an oscilloscope as the default recovery step.

## 4. Body/dome handshake, lights and audio

With servo fuses still out, connect CH3/CH6 to ESP32 RX16/TX17. Fit D-LOGIC3A. Confirm both link directions, fresh channel snapshots and separate left/right VESC records when available.

Connect to Wi-Fi `AstroPixels` / `Astromech`, dashboard `http://192.168.4.1`. Lighting and Wi-Fi must boot even with body offline; body actions must then be rejected visibly.

Prepare DFPlayer's FAT32 card with folder `/01`. At boot the Teensy resets the DFPlayer, retries every 5s until it answers, then sets volume 10/30. Audio stays `Offline` until the player answers. Request a track and confirm accepted -> playback started -> completion in diagnostics. Disconnect DFPlayer TX with power off and repeat: a track the player never confirms ends with a timeout after 2s; software must not claim confirmed playback without feedback. Check the isolator wiring and neither amplifier speaker terminal is grounded.

## 5. Dome and holo motion, unloaded first

Fit B-SERVO 5A with dome drive mechanically disengaged.

1. Calibrate servo neutral pulse until there is no creep. Check both directions, then centered stop.
2. Keep pulse-sleep disabled until the installed servo's signal-loss behaviour is tested. Test loss of pulses with gear disengaged; record whether it stops.
3. Test a deliberate Teensy firmware stall/reset with the dome unloaded. The VESC 150ms timeout does not stop this servo; the hardware watchdog reset target is 1second.
4. With receiver fresh, CH6 ON and dome stick centered, request home. A sensor already active must complete without motion. Otherwise pass a magnet over the Hall sensor: body commands neutral and reports completion.
5. Check manual stick motion cancels homing and Leia; a cancelled home must not start audio later.
6. Fit D-SERVO 5A and connect one holo servo at a time. Confirm connector orientation and channel allocation before installing horns. Calibrate mechanical travel so nothing hits its stop.
7. Run all six together through their intended movement. If a terminal, lead or board power connection becomes hot, stop. If a fuse blows, find the short/jam/load issue; do not increase it.

Only engage the dome drive after unloaded checks pass. Run several full dome rotations and watch link/error counters and clearances. Normal Hall-to-neutral command delay target is <=50ms; record actual dome overshoot separately.

### 5.1 Guided commissioning from the dome web pages (/commissioning, /drive)

A blank profile can be taken to "drive + manual dome + auto dome ready and saved" from the web pages and the transmitter alone, with no laptop or USB tether. The Teensy runs every test, collects the evidence and proposes values. You confirm each group with an explicit **Accept … & Save** click; nothing is accepted for you.

1. **Access the web interface:**
   - Connect your phone, tablet, or laptop to Wi-Fi SSID `AstroPixels` (password `Astromech`).
   - Open `http://192.168.4.1/commissioning`, or select **Commissioning** from the main web menu. **Drive commissioning** on that page opens `/drive` for the feet.
   - The status lines (test state, wizard, wheel-test result, VESC readouts, radio and audio checks, next step) update by themselves about every 0.15 s on `/drive` and 0.5 s on `/commissioning`. Reload only to refresh the field table and checklist, and never on `/drive` while a wheel test runs.
2. **What the pages show:**
   - `/commissioning`: the checklist (17 items, ticked from the **saved** acceptance bits plus this session's radio/failsafe/audio results) with **Next step**, Hall sensor states and ages, the RC snapshot, the current test, the gates, the dome profile fields (servo min/max, auto speed, CW/CCW rates; staged values, edit in place) and the **Wizard** status line (Running / Done / Failed with the body's error code).
   - `/drive`: detected firmware and live telemetry for each VESC, the named profile fields including the recorded firmware, values layout and VESC timeout (staged values, edit in place), the wheel-test buttons, **Last wheel test** (result, stop time next to the staged VESC timeout, peak current, peak eRPM) and "Profile: saved / unsaved changes".
3. **Radio during commissioning:** every test, field edit, Accept and Save needs fresh radio frames, **CH6 (SwA) OFF**, all three motion sticks (CH1, CH2, CH4) centred and no motion lock. **CH9 is not used during commissioning**: SwD may be in either position. Touching a stick, flipping SwA DOWN, losing the radio or a STOP cancels a running test. Motion buttons also need the dome rearmed after a STOP (centre the dome stick).
4. **Guided flow (do the steps in this order):**
   1. **Apply baseline** (`/commissioning`). This fills only the fields that are unset with the recommended baseline (servo 1500/1000/2000 µs, auto speed 15 %, slew 500 ‰/s, VESC currents, voltage limits, 150 ms timeout, timeout brake and reversal settings, and each wheel's firmware as the Teensy observed it). It never overwrites a value you set and never accepts anything. `direction` and the dome rates stay unset; the tests set them.
   2. **Compare with VESC Tool** (`/drive`). For each controller, check the detected firmware and the staged fields against VESC Tool on that controller, as in [VESC Drive Setup](VESC_DRIVE_INTEGRATION.md). Edit any field that differs.
   3. **Accept VESC config & Save** (`/drive`). This accepts `vesc_config` left and right (bits 4/5) and saves. The wheel tests need it saved, because they run on the saved settings.
   4. **Raise both wheels** clear of the floor and tick **Wheels are raised**. The tick covers one test only: it clears as soon as a test starts, so tick it again before every wheel test.
   5. **Wheel tests, for each wheel (L, then R):**
      - **Timeout test**: spins at 10 % duty for 1 s, then stops sending commands. It passes when the VESC's own 150 ms timeout brake brings the wheel below 10 % of its spin speed within 1.5 s.
      - **Direction test**: spins at +10 % duty for 1.5 s, then brakes. Watch the foot, then answer with **L/R rolled forward** or **L/R rolled backward**. The answer stages `direction`, and the direction sign-off needs it.
      - **Reversal test**: spins at +10 % duty for 1 s, brakes at the saved brake current until the wheel stays below the reversal eRPM for the reversal dwell, spins at −10 % duty for 1 s, then brakes. It passes when the eRPM sign reverses at turning speed.
      Before the next test, wait until **Last wheel test** shows the result and the wheel has stopped. A test asked for while the wheel still turns (100 eRPM or more) is refused with error 14.
   6. **Accept wheel tests & Save** (`/drive`). This accepts `timeout_brake`, `direction` and `reversal` for both wheels (bits 6–11) and saves. Each bit needs that wheel's passed automated test, run on saved settings that still match the staged ones. Direction also needs your answer. A bit without evidence is refused, the rest are still accepted, and the Save always runs; the Wizard line then shows the first refusal. Changing a VESC field afterwards clears the sign-offs that depend on it. Save the change, then run those tests again.
   7. **Neutral hold** (`/commissioning`, dome drive gear disengaged). The servo holds the staged `servo_neutral` pulse for 3 s while you watch the shaft. If it creeps, use **Nudge −5us / +5us**. Each nudge stages the new trim and restarts the 3 s hold.
   8. **Accept neutral & Save** once the shaft stays still. The dome servo receives pulses, and the CH4 stick works, only after this Save.
   9. **Calibrate dome (refs + timing)**, with the dome drive engaged and clear to turn. The wizard runs Front reference, Rear reference, Timing CW and Timing CCW in turn. The two timing runs each time three revolutions and stage the median rate (fields 19/20). It stops at the first failure and shows its error.
   10. **Accept dome & Save**. This accepts the front reference, rear reference and timing (bits 1–3) and saves. Each one needs a completed run made with the servo and auto-speed settings that are staged now.
   11. **Start radio check** (`/commissioning`, wheels still raised: SwA goes DOWN during the check). Follow each prompt within 15 s (the Radio line shows the next one by itself): with SwA UP, right stick up, right stick right, left stick right (a stick prompt does not count while SwA is DOWN); then SwA DOWN, SwC through all three positions, SwB DOWN, SwD DOWN, VrA fully both ways. Then set SwA, SwB and SwD DOWN and **turn the transmitter OFF**. The check passes when the failsafe frames show centred sticks and CH6/CH8/CH9 low. It also passes if the receiver stops sending frames ("receiver stops output"); the drive still disarms on stale radio. The transmitter-off row in the failure matrix (section 7) is still the acceptance test for the failsafe. If auto dome is already saved and SwD was UP, the SwD DOWN prompt is the OFF→ON that arms auto dome (item 5), so the dome may turn: keep clear of it (the prompt says so too). SwB macros are suppressed while the check is prompting, so the SwB DOWN prompt fires nothing; if SwB is still DOWN when the check ends, flip it UP before the next macro.
   12. **Audio check**. This plays track 255, and passes when the DFPlayer reports playback within 3 s.
   The checklist's last item, **Save profile**, is ticked when nothing is left unsaved.
5. **Auto dome after the Save that enables it:** the Save that makes auto dome ready does not start the dome by itself. Auto dome (startup alignment, seeks, idle wandering) waits until CH9 (SwD) is seen OFF and then ON. A droid that boots with SwD already ON behaves as before.
6. **Wheel-test safety gates:** a wheel test starts only when all of these hold:
   - fresh radio, CH6 OFF, sticks centred and no motion lock;
   - **Wheels are raised** ticked for this test;
   - that wheel's `vesc_config` accepted **and saved**, its firmware matching the saved record, and fresh, fault-free VESC telemetry (otherwise error 12, not ready);
   - the wheel not already turning (otherwise error 14);
   - no other test running or braking out.
   During the test, only the tested wheel takes commands: duty is capped at 10 % and brake at the saved brake current. The other wheel is held disabled, and no run lasts longer than 6 s. The browser keepalive keeps the test going: while `/drive` is open its live status poll is a heartbeat about every 150 ms, and the dome forwards a keepalive to the body every 100 ms only while the last heartbeat is at most 500 ms old. The body must receive a keepalive at least every 300 ms. Closing the tab, leaving `/drive`, reloading it or losing Wi-Fi therefore brakes the wheel within about 0.8 s, so keep the page open and watch the result line, which updates by itself. (Dome tests keep a dome-driven keepalive and do not need the page.) A lost keepalive, a SwA flip, a stick touch, stale radio, a VESC fault or stale telemetry brakes the wheel for 300 ms and ends the test as Cancelled, TimedOut or Failed.
7. **Other interlocks:**
   - **Emergency cancel:** **Cancel** on either page ends the test. A dome test stops the servo at its accepted neutral (or sends no pulses before that); a wheel test brakes out. If the Wizard line shows "Cancel not sent", press it again.
   - **Inert boot guard:** until the servo neutral is accepted and saved, the dome servo receives no pulses and the CH4 stick does nothing. Until all eight VESC sign-offs are accepted and saved, the feet stay disarmed.

## 6. VESC commissioning and foot drive

Follow [VESC Drive Setup](VESC_DRIVE_INTEGRATION.md) for each independent USB/UART and motor. Keep both wheels elevated. Configure and verify both controllers' firmware/layout, currents, voltage limits,150ms timeout and timeout braking before saving an enabled profile.

### Stationary USB firmware and telemetry verification

Before enabling foot drive, verify that the Teensy correctly negotiates telemetry with both VESC controllers over their direct UART links. Teensy startup queries firmware versions and telemetry values; verify that the decoded fields match VESC Tool before saving an enabled profile.

1. Switch off and disconnect battery, charger and USB before removing the dome. Unplug body-side ring connectors, release the post fastener, and lift vertically to disengage the restraint. Access Teensy and both VESC USB ports at the top of the body; no cut shell panel or permanent external USB port is needed. Secure both wheels clear of the floor, inhibit foot drive (CH6 OFF, centered sticks) and inhibit dome motion (CH9 OFF, dome drive disengaged). Keep the cutoff reachable.
2. Verify the Teensy VUSB/VIN isolation above before using external body power with USB. With the dome removed and all motion inhibited, power the electronics and open Teensy's USB monitor at 115200 baud. Never rotate with an external USB/data/programming tether attached. Do not use old ESP32 VESC commands on this harness.
3. Type **one character** for one validated raw reply: `L` = left FW_VERSION, `R` = right FW_VERSION, `l` = left GET_VALUES, `r` = right GET_VALUES. Firmware is queried first and rechecked periodically; values are polled at 100ms intervals with only one outstanding request per UART. The monitor ignores line-ending characters. Wait for the complete report before requesting the next packet. A disconnected UART may yield no capture; that is not success.
4. Save all `VESC_RAW wheel=… offset=… length=… HEX…` lines for that packet. Concatenate the hexadecimal chunks in increasing offset order; `length` is the full frame length (not payload length). Each loop prints at most 16 captured bytes only when USB has buffer space; no continuous trace or actuator test is started. Capture both FW_VERSION and GET_VALUES separately for **each** controller. Retain controller identity, date, firmware/version, full raw bytes, decoded values, VESC Tool version and comparison notes as the fixture's provenance.
5. Strip the short (`02`, one-byte length) or long (`03`, two-byte big-endian length) header, CRC and `03` terminator for decoding. The FW payload starts `00 major minor`. Named layout **1 / kLayoutLegacyGetValues** has payload offsets including command byte: MOSFET signed dC at 1; motor/input signed current at 5/9 (wire 0.01A -> mA by multiplying by 10); signed duty permille at 21; signed eRPM at 23; signed voltage at 27 (wire 0.1V -> cV by multiplying by 10); fault byte at 53. Motor TEMP at 3 is not connected and is **invalid**, not a usable temperature. CRC and terminator must validate; required fields must fit their body-message representation.
6. Using each controller's stationary USB connection, compare the observed firmware and decoded voltage, MOSFET temperature, signed motor/input current, duty, eRPM and fault against **VESC Tool** on that same controller under stable conditions. Record differences and units; queries sample averaged current, so note timing differences rather than inventing agreement. Verify current sign and scaling during low-speed bench testing under light load before floor driving. Check the actual installed firmware's GET_VALUES layout if any field disagrees. Do not select a profile from length alone.
7. Only after the comparison passes, check that wheel's fields on `/drive` (6 `fw_major`, 7 `fw_minor`, 8 `layout` = 1, currents 9-12, voltages 13/14, 15 `timeout_ms` = 150, 16 `timeout_brake_ma`, 17/18 reversal; **Apply baseline** fills any that are unset) and press **Accept VESC config & Save** (bits 4/5), with CH6 OFF and sticks centred. Set/save does not imply acceptance, and changing a field clears the sign-offs that depend on it. Actuator writes additionally require `timeout_brake` (6/7), `direction` (8/9) and `reversal` (10/11). Those bits are accepted only from a passed automated wheel test on the raised wheel (section 5.1, steps 4-6), then **Accept wheel tests & Save**. The drive uses the saved profile without a reboot. Verify current limits and braking behaviour according to the commissioned power budget.
8. Disconnect all external USB/data/programming cables and power before reassembly. Reconnect the keyed ring connectors and restraint, then verify clearances unpowered. Use the wireless commissioning page for installed rotation checks; **no rotating tether**.

Set CH6 OFF. Center steering/throttle, turn CH6 ON, keep centered 500ms, then check low-rate movement and wheel direction. A controller fault or stale feedback stops both wheels and requires OFF -> ON -> neutral rearming.
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

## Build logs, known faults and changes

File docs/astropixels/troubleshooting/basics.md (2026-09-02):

> For the complete documentation index, see [llms.txt](https://r2djp.gitbook.io/astropixels/llms.txt). Markdown versions of documentation pages are available by appending `.md` to page URLs; this page is available as [Markdown](https://r2djp.gitbook.io/astropixels/troubleshooting/basics.md).

# Basics

This page will walk you through some basic troubleshooting steps. If you are having issues then these are the steps I will ask you to follow so we can figure out what is wrong.

### Wrong colours

If you are seeing the wrong colours and/or not all lights lighting up, there is a chance you have the wrong board connected to the wrong header. Double check the lights boards correspond to the labels on the motherboard.

### Not lighting up

If its just a single board not lighting up, make sure the cable is the correct way round. Signal (row labelled with 'S') should go to signal (or data) on the light board. It is also worth trying the board on another header (such as the RLD) to see if it lights up. If it does, that proves the light board is ok and it may be a dead pin on the ESP32.

If nothing is lighting, double check all wiring and that power is good. There should at least be a red light on the ESP32.

### Only lighting up a few LEDs.

If you've definitely got it connected to the correct header but nothing after a certain LED is lighting, then you may have a faulty light board. If a single pixel goes, then 99% of the time nothing after it will work either. Get in touch and I'll get a replacement sorted.

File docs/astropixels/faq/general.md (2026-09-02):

> For the complete documentation index, see [llms.txt](https://r2djp.gitbook.io/astropixels/llms.txt). Markdown versions of documentation pages are available by appending `.md` to page URLs; this page is available as [Markdown](https://r2djp.gitbook.io/astropixels/faq/general.md).

# General

### Why did you create the Astropixels?

Initially to just have a go at designing PCBs. I did the first PSIs and got them manufactured by JLCPCB and realised how easy it was and also just how cheap I could make them if ordering in bulk. So I did the rest of the dome light boards, using the ReelTwo library and the Astropixels were born. It was also a way to give people an upgrade that is both better and cheaper than the common teecees lights that are using very old tech. You can see a comparison of them here.

### How long did it take?

It took me a couple of months and a number of failed attempts to get the first batch made that I sold to some beta testers in the UK. I then started ramping up the production numbers, with a few tweaks to the design until about a year later I had what is now the current version.

### Why so cheap?

I get a lot of people asking this, and the answer is that I’m doing this for the love of the club. I’ve taken a lot from other members over the years with all the information and parts that they willingly share so I thought it was time to return the favour for the new people in the club. I don’t aim to make any money from this, so apart from making sure I’ve enough spares and that I’m not out of pocket I will keep the price as cheap as possible.

### Do these fit into the Home Depot R2D2?

No, the Home Depot R2 is not full size. These lights are designed to fit into a full sized replica. Some people have got them to fit, but it will take some serious hacking with a dremel.

### Will you make some for the Home Depot R2D2?

Almost certainly no. I can just about keep up with demand for full sized droids being built by the Builders Club. I don't have the time to do a redesign. The Home Depot R2 is also not available in this country, so I would be working blind. Lastly, as per the questions above, I do this for the love of the club to help people build droids that go out in public for charity and I don't personally make much money from them.

### If I buy some and try to fit them into the Home Depot R2D2 but fail, will you take them back?

No. If you've bought them after all these warnings, then it is on you.

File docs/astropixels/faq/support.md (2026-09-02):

> For the complete documentation index, see [llms.txt](https://r2djp.gitbook.io/astropixels/llms.txt). Markdown versions of documentation pages are available by appending `.md` to page URLs; this page is available as [Markdown](https://r2djp.gitbook.io/astropixels/faq/support.md).

# Support

### I’ve a faulty board, can you help?

Of course! Drop me a line and we can try some basic trouble shooting. If it turns out there is a faulty part I will get a replacement out to you asap.

### Can I integrate the Astropixels with ?

There are lots of options for integration with various control systems. However, I can’t possibly know everything about them. There is documentation on how to send commands to the Astropixels to trigger effects but it is up to you to figure it out. Some people have worked with common systems such as the Marcduino and there is lots of documentation on the internet on how to do it. I ship the Astropixels with the most basic of code as that is what the vast majority of people want. There is an AstroPixelsPlus firmware available that another club member has written that extends the functionality. At the end of the day, I’m providing some hardware for as cheap as possible. There are lots of capabilities that can be added. Of course you’re welcome to message me and I’ll certainly try to help.

### I’m building a scale R2 (bigger/smaller), can you sell me lights for them?

Unfortunately, no. Theres a lot of work and money that goes into developing the boards and I simply do not have the time. There is a reason my own projects are not finished!

### Can you sell me some lights with different colours and/or startup text?

The sets are usually already boxed up and ready to ship when stock is on the store, so I don’t offer any custom programming options. However there are instructions on this site on how to customise your Astropixels. Its fairly easy and I recommend anyone building a droid be familiar with basic Arduino programming anyway.

### Have you a video or diagram to show how to put these together?

Nope, I don’t like to do videos or anything like that, and have not managed to make a diagram that I’m happy with. But if someone wants to make one then I’ll happily share that. I do also suck at documentation, and I know I need to improve on that somewhat. This is an ongoing project (and part of the reason I’m writing this FAQ)

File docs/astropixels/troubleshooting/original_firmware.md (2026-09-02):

> For the complete documentation index, see [llms.txt](https://r2djp.gitbook.io/astropixels/llms.txt). Markdown versions of documentation pages are available by appending `.md` to page URLs; this page is available as [Markdown](https://r2djp.gitbook.io/astropixels/troubleshooting/original_firmware.md).

# Original Firmware

If you have been messing with the firmware and want to go back to the basics, the example Astropixels sketch in the ReelTwo library is what is installed by default when they are shipped.

I have also created a web installer that you can use:

[Web Installer](https://dpoulson.github.io/Astropixels/)

The standard firmware is what is shipped by default with all Astropixels.

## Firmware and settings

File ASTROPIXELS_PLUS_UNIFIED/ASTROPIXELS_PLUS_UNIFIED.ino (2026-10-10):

/*
 * ═══════════════════════════════════════════════════════════════════════════════
 *                 ASTROPIXELS PLUS - UNIFIED R2-D2 DOME BRAIN
 *     (ReelTwo OS + Bi-Directional Body Link + Wi-Fi Web GUI + OTA + Choreography)
 * ═══════════════════════════════════════════════════════════════════════════════
 *
 * Target Board:   ESP32 Dev Module (30-pin, AstroPixels Motherboard)
 * Architecture:   Cooperative control loop interfacing with Teensy 4.1 Body Controller
 *
 * Core Allocations:
 *   • Networking & Web Interface:
 *       1. Wi-Fi SoftAP ("AstroPixels" / "Astromech") & Station Client
 *       2. Web Server (Port 80) serving interactive GUI at http://192.168.4.1
 *       3. Telemetry page (/diagnostics) and Wireless Commissioning (/commissioning)
 *       4. ArduinoOTA Wireless Firmware Flashing (gated by Teensy maintenance lock)
 *       5. Wi-Fi MarcDuino UDP Receiver
 *
 *   • Peripherals & Interfaces:
 *       1. Hardware UART2 (115,200 baud / GPIO 16 RX, GPIO 17 TX): Bi-directional
 *          SLIP protocol link to Teensy 4.1 Body Controller via Slip Ring CH3/CH6
 *       2. Dual KY-003 Hall Sensors (GPIO 19 Front, GPIO 18 Rear via LLC):
 *          Published Hall telemetry for body-controlled homing and calibration
 *       3. PCA9685 I2C 16-Ch Controller (Addr 0x40 / GPIO 21, 22): 6 HoloProjector servos (Ch 0-5)
 *       4. ReelTwo LogicEngine: Movie-accurate FLD1/2, RLD, FPSI, RPSI & text scrolling
 *       5. ReelTwo HoloLights: WS2812 Holo LEDs with dim pulses, rainbow & Leia flicker
 *       6. Procedural Shaders: Plasma, MetaBalls, Fractal, and Bitmap animations
 *
 * ═══════════════════════════════════════════════════════════════════════════════
 */

#define USE_DEBUG
#define USE_WIFI
#define USE_SPIFFS

#ifdef USE_WIFI
#define REMOTE_ENABLED false // Default off; enable in prefs if pairing Droid Remote
#define WIFI_ENABLED   true  // Wi-Fi Access Point enabled by default
#define WIFI_AP_NAME   "AstroPixels"
#define WIFI_AP_PASSPHRASE "Astromech"
#define WIFI_ACCESS_POINT  true /* true = soft AP; false = join existing Wi-Fi */

#define USE_MDNS
#define USE_OTA
#define USE_WIFI_WEB
#define USE_WIFI_MARCDUINO
#endif

#define SMQ_HOSTNAME "Astro"
#define SMQ_SECRET   "Astromech"

/////////////////////////////////////////////////////////////////////////

#include "ReelTwo.h"
#include "dome/Logics.h"
#include "dome/LogicEngineController.h"
#include "dome/HoloLights.h"
#include "dome/NeoPSI.h"
#include "dome/FireStrip.h"
#include "dome/BadMotivator.h"
#include "ServoDispatchPCA9685.h"
#include "ServoSequencer.h"
#include "core/Marcduino.h"

#include <Preferences.h>
#include <Wire.h>

/////////////////////////////////////////////////////////////////////////
// 1. PIN DEFINITIONS & HARDWARE CONSTANTS
/////////////////////////////////////////////////////////////////////////

// Serial Communication to Teensy 4.1 Body Controller via Slip Ring
#define PIN_BODY_UART_RX     16    // Hardware Serial2 RX (115,200 baud): Body Controller via Slip Ring CH3
#define PIN_BODY_UART_TX     17    // Hardware Serial2 TX (115,200 baud): Body Controller via Slip Ring CH6
#define BODY_SERIAL          Serial2

// Dome Dual Hall Sensor Inputs (KY-003 via LLC)
#define PIN_DOME_HALL_FRONT  19    // Digital Input: Front Hall Sensor 0° (AUX 5 via LLC LV2)
#define PIN_DOME_HALL_REAR   18    // Digital Input: Rear Hall Sensor 180° (AUX 4 via LLC LV3)

// I2C Pins (PCA9685 Servo Controller)
#define PIN_SDA              21
#define PIN_SCL              22
#define PCA9685_I2C_ADDR     0x40

// FastLED / ReelTwo WS2812 Pin Assignments (Matches AstroPixels Factory Hardware)
#define PIN_FRONT_LOGIC      15    // Front Logic Displays (daisy-chained FLD1 -> FLD2)
#define PIN_REAR_LOGIC       33    // Rear Logic Display (RLD)
#define PIN_FRONT_PSI        32    // Front Process State Indicator (FPSI)
#define PIN_REAR_PSI         23    // Rear Process State Indicator (RPSI)
#define PIN_FRONT_HOLO       25    // Front HoloProjector LED Core (7 LEDs)
#define PIN_REAR_HOLO        26    // Rear HoloProjector LED Core (7 LEDs)
#define PIN_TOP_HOLO         27    // Top HoloProjector LED Core (7 LEDs)

// Spare AUX Pins
#define PIN_AUX1             2
#define PIN_AUX2             4
#define PIN_AUX3             5

/////////////////////////////////////////////////////////////////////////
// 2. BODY LINK CLIENT & REMOTE HARDWARE ADAPTERS
/////////////////////////////////////////////////////////////////////////

#include "BodyClient.h"
#include "RemoteAudio.h"
#include "DomeBehaviour.h"

class Esp32SerialPort : public r2link::BytePort {
public:
    explicit Esp32SerialPort(HardwareSerial& serial) : serial_(serial) {}
    int read() override { return serial_.read(); }
    size_t writable() const override {
        const int n = serial_.availableForWrite();
        return n > 0 ? size_t(n) : 0;
    }
    size_t write(const uint8_t* data, size_t length) override {
        const size_t capacity = writable();
        if (length > capacity) length = capacity;
        return length ? serial_.write(data, length) : 0;
    }
private:
    HardwareSerial& serial_;
};

class Esp32DomeRandom : public IDomeRandom {
public:
    int32_t pick(int32_t min_inclusive, int32_t max_exclusive) override {
        if (min_inclusive >= max_exclusive) return min_inclusive;
#if defined(ESP32)
        return min_inclusive + (int32_t)(esp_random() % (uint32_t)(max_exclusive - min_inclusive));
#else
        return min_inclusive + (int32_t)(rand() % (max_exclusive - min_inclusive));
#endif
    }
};

static Esp32SerialPort g_body_port(BODY_SERIAL);
static BodyClient g_body_client;
static RemoteAudio g_remote_audio(g_body_client);
static Esp32DomeRandom g_dome_random;
static DomeBehaviour g_dome_behaviour(g_body_client, g_dome_random, 25);

// Guided commissioning tools (web pages /commissioning and /drive).
#include "ProfileMirror.h"
#include "CommissionWizard.h"
#include "RadioCheck.h"
#include "AudioCheck.h"
#include "CommissionChecklist.h"
#include "CommissionKeepalive.h"
static ProfileMirror g_profile_mirror(g_body_client);
static CommissionWizard g_wizard(g_body_client);
static RadioCheck g_radio_check;
static AudioCheck g_audio_check;
static bool g_wheels_raised = false;
static BrowserHeartbeat g_drive_heartbeat;   // /drive page open: wheel tests may keep running

#define MARC_SOUND_PLAYER    MarcSound::kDFMini
#define MARC_SOUND_VOLUME    333   // 0 - 1000; ceil(333 / 1000 * 30) = 10
#define MARC_SOUND_STARTUP   255   // Track 255 (startup chime)
#define MARC_SOUND_RANDOM    true  // Ambient background chatter enabled
#define MARC_SOUND_RANDOM_MIN 5000
#define MARC_SOUND_RANDOM_MAX 25000

/////////////////////////////////////////////////////////////////////////
// 4. PREFERENCES (NVS FLASH STORAGE)
/////////////////////////////////////////////////////////////////////////

#define PREFERENCE_WIFI_ENABLED      "wifi"
#define PREFERENCE_WIFI_SSID         "ssid"
#define PREFERENCE_WIFI_PASS         "pass"
#define PREFERENCE_WIFI_AP           "ap"
#define PREFERENCE_MARCSOUND         "msound"
#define PREFERENCE_MARCSOUND_VOLUME  "mvolume"
#define PREFERENCE_MARCSOUND_STARTUP "msoundstart"
#define PREFERENCE_MARCSOUND_RANDOM  "mrandom"
#define PREFERENCE_MARCSOUND_RANDOM_MIN "mrandommin"
#define PREFERENCE_MARCSOUND_RANDOM_MAX "mrandommax"

#define CONSOLE_BUFFER_SIZE          300

/////////////////////////////////////////////////////////////////////////
// 5. REELTWO WI-FI, WEB SERVER & OTA HEADERS
/////////////////////////////////////////////////////////////////////////

#include "wifi/WifiAccess.h"

#ifdef USE_MDNS
#include <ESPmDNS.h>
#endif
#ifdef USE_WIFI_WEB
#include "wifi/WifiWebServer.h"
#endif
#ifdef USE_WIFI_MARCDUINO
#include "wifi/WifiMarcduinoReceiver.h"
#endif
#ifdef USE_OTA
#include <ArduinoOTA.h>
#endif
#ifdef USE_SPIFFS
#include "SPIFFS.h"
#define USE_FS SPIFFS
#endif
#include "FS.h"

/////////////////////////////////////////////////////////////////////////
// 6. REELTWO DISPLAY & HOLO INSTANCES
/////////////////////////////////////////////////////////////////////////

AstroPixelRLD<PIN_REAR_LOGIC> RLD(LogicEngineRLDDefault, 3);
AstroPixelFLD<PIN_FRONT_LOGIC> FLD(LogicEngineFLDDefault, 1);
AstroPixelFrontPSI<PIN_FRONT_PSI> frontPSI(LogicEngineFrontPSIDefault, 4);
AstroPixelRearPSI<PIN_REAR_PSI> rearPSI(LogicEngineRearPSIDefault, 5);

HoloLights frontHolo(PIN_FRONT_HOLO, HoloLights::kRGB, 1);
HoloLights rearHolo(PIN_REAR_HOLO, HoloLights::kRGB, 2);
HoloLights topHolo(PIN_TOP_HOLO, HoloLights::kRGB, 3);

/////////////////////////////////////////////////////////////////////////
// 7. PCA9685 16-CH SERVO MAPPING (SINGLE CONTROLLER: 6 HOLO SERVOS)
/////////////////////////////////////////////////////////////////////////

#define HOLO_HSERVO 0x1000
#define HOLO_VSERVO 0x2000
#define ALL_DOME_PANELS_MASK 0 // No physical dome door panels on this droid

const ServoSettings servoSettings[] PROGMEM = {
    { 0, 1000, 2000, HOLO_HSERVO }, /* Ch 0: Front Holo Horizontal (Pan) */
    { 1, 1000, 2000, HOLO_VSERVO }, /* Ch 1: Front Holo Vertical (Tilt) */
    { 2, 1000, 2000, HOLO_HSERVO }, /* Ch 2: Rear Holo Horizontal (Pan) */
    { 3, 1000, 2000, HOLO_VSERVO }, /* Ch 3: Rear Holo Vertical (Tilt) */
    { 4, 1000, 2000, HOLO_HSERVO }, /* Ch 4: Top Holo Horizontal (Pan) */
    { 5, 1000, 2000, HOLO_VSERVO }  /* Ch 5: Top Holo Vertical (Tilt) */
};

enum R2Macro : uint8_t { R2_NONE, R2_SCREAM, R2_CANTINA, R2_LEIA, R2_DISCO, R2_FAINT };

enum class MacroPhase : uint8_t {
    Idle = 0,
    WaitingHome,
    WaitingAudio,
    Running,
    Finishing
};

struct MacroState {
    MacroPhase phase{MacroPhase::Idle};
    R2Macro kind{R2_NONE};
    uint16_t home_sequence{0};
    uint16_t audio_sequence{0};
    bool dome_cancelled{false};
    uint32_t dome_generation{0};
    uint32_t guard_deadline_ms{0};
    uint32_t started_ms{0};
    uint32_t duration_ms{0};
    uint32_t last_step{UINT32_MAX};
};

enum class MaintenanceState : uint8_t {
    Idle = 0,
    Requested,
    Locked,
    Updating,
    Failed,
    Releasing
};

struct MaintenanceInfo {
    MaintenanceState state{MaintenanceState::Idle};
    uint16_t token{0};
    uint16_t sequence{0};
    uint32_t deadline_ms{0};
    bool pending_reboot{false};
    bool clear_prefs_on_reboot{false};
};

extern MacroState macro;
extern MaintenanceInfo g_maintenance;
extern R2Macro& active_macro;

void startR2Macro(R2Macro macro);
void stopDomeMotion();
void emergencyStop();
void releaseBodyStop();
void cancelR2Macro();
void finishR2Macro();
void disableHoloServos();
bool r2MacroActive();
void startDomeHoming(R2Macro macro = R2_NONE);
void playDFPlayerTrack(uint16_t track_num);
bool maintenanceReady();
void prepareMaintenance(bool for_reboot = false, bool clear_prefs = false);
void releaseMaintenance();
void recoverBodyLocks();
void clearPrefsAndReboot();
void startCommissionTest(uint8_t test, int32_t val = 0);
void acceptCommissionBit(uint8_t bit);
void setCommissionField(uint8_t field, uint8_t wheel, int32_t value);
void onOtaStart();
void readCommissionField(uint8_t field, uint8_t wheel);
bool prepareCommissionMotion();
void startAudioCheck();
ChecklistInput checklistInput();

ServoDispatchPCA9685<SizeOfArray(servoSettings)> servoDispatch(servoSettings);
ServoSequencer servoSequencer(servoDispatch);
AnimationPlayer player(servoSequencer);
MarcduinoSerial<> marcduinoSerial(player);

/////////////////////////////////////////////////////////////////////////
// 8. PROCEDURAL SHADERS & SOUND SYSTEM
/////////////////////////////////////////////////////////////////////////

#include "MarcduinoSound.h"
MarcSound::Module sSoundPlayer;

#define NUM_LEDS 28 * 4
CRGB leds[NUM_LEDS];

enum {
    SDBITMAP = 100,
    PLASMA,
    METABALLS,
    FRACTAL,
    FADEANDSCROLL
};

#include "effects/BitmapEffect.h"
#include "effects/FadeAndScrollEffect.h"
#include "effects/FractalEffect.h"
#include "effects/MeatBallsEffect.h"
#include "effects/PlasmaEffect.h"

LogicEffect CustomLogicEffectSelector(unsigned selectSequence) {
    static const LogicEffect sCustomLogicEffects[] = {
        LogicEffectBitmap,
        LogicEffectPlasma,
        LogicEffectMetaBalls,
        LogicEffectFractal,
        LogicEffectFadeAndScroll
    };
    if (selectSequence >= 100 && selectSequence - 100 < SizeOfArray(sCustomLogicEffects)) {
        return LogicEffect(sCustomLogicEffects[selectSequence - 100]);
    }
    return LogicEffectDefaultSelector(selectSequence);
}

Preferences preferences;

bool mountReadOnlyFileSystem() {
#ifdef USE_SPIFFS
    return (SPIFFS.begin(true));
#endif
    return false;
}

void unmountFileSystems() {
#ifdef USE_SPIFFS
    SPIFFS.end();
#endif
}

void reboot() {
    DEBUG_PRINTLN("[SYSTEM] Restarting...");
    prepareMaintenance(true, false);
}

void clearPrefsAndReboot() {
    DEBUG_PRINTLN("[SYSTEM] Clearing preferences and restarting...");
    prepareMaintenance(true, true);
}

void resetSequence() {
    CommandEvent::process(F(
        "LE000000|0\n" // LogicEngine devices to normal
        "HPA000|0\n"
    ));
}

int32_t strtol(const char *cmd, const char **endptr) {
    bool sign = false;
    int32_t result = 0;
    if (*cmd == '-') { cmd++; sign = true; }
    while (isdigit(*cmd)) {
        result = result * 10L + (*cmd - '0');
        cmd++;
    }
    *endptr = cmd;
    return (sign) ? -result : result;
}

bool numberparams(const char *cmd, uint8_t &argcount, int32_t *args, uint8_t maxcount) {
    for (argcount = 0; argcount < maxcount; argcount++) {
        args[argcount] = strtol(cmd, &cmd);
        if (*cmd == '\0') { argcount++; return true; }
        else if (*cmd != ',') return false;
        cmd++;
    }
    return true;
}

/////////////////////////////////////////////////////////////////////////
// 9. MARCDUINO COMPATIBILITY HEADERS
/////////////////////////////////////////////////////////////////////////

#include "MarcduinoHolo.h"
#include "MarcduinoLogics.h"
#include "MarcduinoSequence.h"
#include "MarcduinoPSI.h"

#ifdef USE_WIFI
WifiAccess wifiAccess;
bool wifiEnabled;
bool wifiActive;
bool otaInProgress;
#endif

#ifdef USE_WIFI_MARCDUINO
WifiMarcduinoReceiver wifiMarcduinoReceiver(wifiAccess);
#endif

#ifdef USE_WIFI_WEB
#include "WebPages.h"
#endif

/////////////////////////////////////////////////////////////////////////
// 10. FLYSKY i-BUS & DOME HOMING STATE MACHINE
/////////////////////////////////////////////////////////////////////////

// RC Channel Buffer (Channels 1 to 10 in microseconds: 1000us - 2000us)
uint16_t rc_channels[10] = {1500, 1500, 1500, 1500, 1500, 1500, 1500, 1500, 1500, 1500};
bool rc_connected = false;
unsigned long last_rc_packet_ms = 0;

// FlySky FS-i6X Channel Mapping
#define RC_CH_STEER            0  // Right Stick X (CH1): Tank Differential Steering
#define RC_CH_THROTTLE         1  // Right Stick Y (CH2): Forward / Reverse Throttle
#define RC_CH_DRIVE_STEER      0
#define RC_CH_DRIVE_THROTTLE   1
#define RC_CH_DOME_STEER       3  // Left Stick X (CH4): Manual Dome Rotation
#define RC_CH_SPEED_MODE       4  // Switch SwC   (CH5, 3-pos): Duty rate 35/70/100%
#define RC_CH_MOOD_SELECT      6  // Knob VrA     (CH7): Persistent Mood & Macro Selector (1-13)
#define RC_CH_MACRO_TRIGGER    7  // Switch SwB   (CH8): Macro Fire Trigger (Flip DOWN)
#define RC_CH_AUTO_DOME        8  // Switch SwD   (CH9): Auto Dome Enable

// Dome Homing & Macro Tracking
enum HomingState : uint8_t {
    HOMING_INACTIVE = 0,
    HOMING_SEEKING,
    HOMING_ALIGNED
};

HomingState homing_state = HOMING_INACTIVE;
R2Macro pending_macro_after_home = R2_NONE;
bool dome_motion_inhibited = true;
MacroState macro{};
MaintenanceInfo g_maintenance{};
R2Macro& active_macro = macro.kind;
uint32_t macro_started_ms = 0;
uint32_t macro_duration_ms = 0;
uint32_t last_macro_step = UINT32_MAX;
uint32_t next_holo_twitch_ms = 0;

// Forward Declarations
void processHallSensors(uint32_t now_ms);
void processBodyRcSnapshot(uint32_t now_ms);
void processTransmitterInputs();
void playDFPlayerTrack(uint16_t track_num);
void stopDomeMotion();
void startDomeHoming(R2Macro macro);
void processMacroCompletion(const r2link::Completion& comp);
void processMacroEvent(const r2link::Event& ev);
void processMaintenanceCompletion(const r2link::Completion& comp);
void processMaintenance(uint32_t now);

bool rcNeutral() {
    return rc_channels[RC_CH_DOME_STEER] >= 1460 &&
           rc_channels[RC_CH_DOME_STEER] <= 1540;
}

bool driveNeutral() {
    return rc_channels[RC_CH_DRIVE_STEER] >= 1460 &&
           rc_channels[RC_CH_DRIVE_STEER] <= 1540 &&
           rc_channels[RC_CH_DRIVE_THROTTLE] >= 1460 &&
           rc_channels[RC_CH_DRIVE_THROTTLE] <= 1540;
}

// Every event-owned dome request carries the body's current control epoch and
// dome authority generation, and the DomeRequest wire owner (not DomeOwner).
RequestHandle sendDomeRequest(r2link::DomeOperation operation, r2link::DomeReference reference) {
    const auto status = g_body_client.bodyStatus(millis());
    r2link::DomeRequest req{};
    req.operation = static_cast<uint8_t>(operation);
    req.reference = (operation == r2link::DomeOperation::SeekReference) ? static_cast<uint8_t>(reference) : 0;
    req.owner = r2link::kDomeRequestOwnerEvent;
    req.control_epoch = status.value.control_epoch;
    req.dome_authority_generation = status.value.dome_authority_generation;
    return g_body_client.requestDome(req, millis());
}

// Dome-local stop: ends macros, homing and holo motion and cancels the dome's own
// remote dome actions. It never latches a body STOP; the body owns RC failsafe.
void stopDomeMotion() {
    homing_state = HOMING_INACTIVE;
    pending_macro_after_home = R2_NONE;
    dome_motion_inhibited = true;
    cancelR2Macro();
    disableHoloServos();
    sendDomeRequest(r2link::DomeOperation::Cancel, r2link::DomeReference::Front);
}

// Operator emergency stop: also latches STOP on the body until it is released.
void emergencyStop() {
    stopDomeMotion();
    const auto status = g_body_client.bodyStatus(millis());
    r2link::ControlRequest creq{};
    creq.operation = 0; // STOP_ALL
    creq.reason = r2link::kReasonOperator;
    creq.token = 0;
    creq.control_epoch = status.value.control_epoch;
    g_body_client.requestControl(creq, millis());
}

void releaseBodyStop() {
    const auto status = g_body_client.bodyStatus(millis());
    r2link::ControlRequest req{};
    req.operation = 1; // RELEASE_STOP (body requires CH6 OFF, sticks centred 500ms)
    req.reason = r2link::kReasonOperator;
    req.token = 0;
    req.control_epoch = status.value.control_epoch;
    g_body_client.requestControl(req, millis());
}

void startDomeHoming(R2Macro macro) {
    if (!rc_connected || dome_motion_inhibited || otaInProgress) {
        Serial.println(F("[HOMING] Rejected: live radio and neutral rearm required."));
        return;
    }
    cancelR2Macro();
    pending_macro_after_home = macro;
    homing_state = HOMING_SEEKING;
    if (!sendDomeRequest(r2link::DomeOperation::SeekReference, r2link::DomeReference::Front).queued) {
        homing_state = HOMING_INACTIVE;
        pending_macro_after_home = R2_NONE;
        Serial.println(F("[HOMING] Rejected: body link not ready."));
        return;
    }
    Serial.println(F("[HOMING] Active 0° Dome Homing Routine Initiated via Body..."));
}

void playDFPlayerTrack(uint16_t track_num) {
    if (track_num == 0 || track_num > 255) {
        Serial.println(F("[AUDIO] Invalid track; expected 1..255 in /01."));
        return;
    }
    g_remote_audio.play(track_num, r2link::AudioPriority::Foreground, millis());
}

void processHallSensors(uint32_t now_ms) {
    static uint32_t last_hall_publish_ms = 0;
    static uint8_t last_active_mask = 0xFF;
    static uint32_t hall_sample_counter = 0;

    // Both KY-003 sensors are active LOW (magnet detected = LOW)
    uint8_t front_active = (digitalRead(PIN_DOME_HALL_FRONT) == LOW) ? 1 : 0;
    uint8_t rear_active = (digitalRead(PIN_DOME_HALL_REAR) == LOW) ? 2 : 0;
    uint8_t active_mask = front_active | rear_active;
    uint8_t valid_mask = 0x03;

    if (active_mask != last_active_mask || (now_ms - last_hall_publish_ms >= 20)) {
        last_active_mask = active_mask;
        last_hall_publish_ms = now_ms;
        ++hall_sample_counter;
        g_body_client.publishHall(valid_mask, active_mask, hall_sample_counter, now_ms);
    }
}
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
void loop() {
    uint32_t now = millis();

    // 1. Tick body client and process incoming frames from Teensy
    g_body_client.tick(now);

    // 2. Drain completions and forward to macros, maintenance and the idle scheduler
    dispatchBodyCompletions();

    // 3. Drain events and forward to DomeBehaviour and macro sequencer
    dispatchBodyEvents();

    // 4. Process maintenance timeouts
    processMaintenance(now);

    // 5. Process commissioning keepalive, the guided tools and the deferred startup sound
    processCommissioningKeepalive(now);
    processCommissioningTools(now);
    processStartupSound(now);
    processHeapReport(now);

    // 3. Dual Hall sensors publish
    processHallSensors(now);

    // 4. Ingest RC snapshot from Teensy
    processBodyRcSnapshot(now);

    // 5. Autonomous dome behaviour scheduler
    DomeBehaviourInput dome_input = g_body_client.makeDomeBehaviourInput(now, active_macro != R2_NONE);
    g_dome_behaviour.tick(dome_input, now);

#ifdef USE_WIFI
    if (wifiActive) {
#ifdef USE_OTA
        ArduinoOTA.handle();
#endif
#ifdef USE_WIFI_WEB
        webServer.handle();
#endif
    }
#endif
    if (otaInProgress) {
        return; // motion was stopped once when the update started
    }

    processTransmitterInputs();
    processRandomHolos();
    AnimatedEvent::process();
    processR2Macro();
    sMarcSound.idle();
}

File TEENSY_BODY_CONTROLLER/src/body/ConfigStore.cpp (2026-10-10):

#include "body/ConfigStore.h"
#include <string.h>
#include "Bytes.h"
#include "Codec.h"

namespace body {

namespace {

const uint8_t kCommitted = 0xA5, kInvalidated = 0x00, kBlank = 0xFF;
const uint32_t kBootMagic = 0x314C5342, kProfileMagic = 0x31465250;
const uint8_t kRecordVersion = 1;

struct Spec { uint8_t id; bool wheel; int32_t lo, hi; };
const Spec kSpecs[] = {
    {0, false, 1400, 1600}, {1, false, 1000, 1499}, {2, false, 1501, 2000}, {3, false, 1, 25},
    {4, false, 1, 1000}, {19, false, 1, 36000}, {20, false, 1, 36000},
    {5, true, -1, 1}, {6, true, 0, 255}, {7, true, 0, 255}, {8, true, 1, 1},
    {9, true, 1, 100000}, {10, true, 1, 20000}, {11, true, 0, 20000}, {12, true, 1, 100000},
    {13, true, 1000, 1500}, {14, true, 1300, 1600}, {15, true, 150, 150}, {16, true, 1, 100000},
    {17, true, 1, 10000}, {18, true, 20, 1000}
};
const size_t kSpecCount = sizeof(kSpecs) / sizeof(kSpecs[0]);

const Spec* specFor(uint8_t id) {
    for (size_t i = 0; i < kSpecCount; ++i) if (kSpecs[i].id == id) return &kSpecs[i];
    return 0;
}

int32_t rawGet(const CommissioningProfile& p, uint8_t id, uint8_t w) {
    const WheelProfile& x = p.wheel[w & 1];
    switch (id) {
        case 0: return p.servo_neutral;
        case 1: return p.servo_min;
        case 2: return p.servo_max;
        case 3: return p.auto_speed_percent;
        case 4: return p.duty_slew_permille_per_s;
        case 19: return p.cw_ddeg_per_s;
        case 20: return p.ccw_ddeg_per_s;
        case 5: return x.direction;
        case 6: return x.fw_major;
        case 7: return x.fw_minor;
        case 8: return x.layout;
        case 9: return static_cast<int32_t>(x.motor_ma);
        case 10: return static_cast<int32_t>(x.battery_ma);
        case 11: return static_cast<int32_t>(x.regen_ma);
        case 12: return static_cast<int32_t>(x.brake_ma);
        case 13: return x.undervoltage_cv;
        case 14: return x.overvoltage_cv;
        case 15: return x.timeout_ms;
        case 16: return static_cast<int32_t>(x.timeout_brake_ma);
        case 17: return x.reversal_erpm_limit;
        case 18: return x.reversal_dwell_ms;
    }
    return 0;
}

void rawSet(CommissioningProfile& p, uint8_t id, uint8_t w, int32_t v) {
    WheelProfile& x = p.wheel[w & 1];
    switch (id) {
        case 0: p.servo_neutral = static_cast<uint16_t>(v); break;
        case 1: p.servo_min = static_cast<uint16_t>(v); break;
        case 2: p.servo_max = static_cast<uint16_t>(v); break;
        case 3: p.auto_speed_percent = static_cast<uint8_t>(v); break;
        case 4: p.duty_slew_permille_per_s = static_cast<uint16_t>(v); break;
        case 19: p.cw_ddeg_per_s = static_cast<uint16_t>(v); break;
        case 20: p.ccw_ddeg_per_s = static_cast<uint16_t>(v); break;
        case 5: x.direction = static_cast<int8_t>(v); break;
        case 6: x.fw_major = static_cast<uint8_t>(v); break;
        case 7: x.fw_minor = static_cast<uint8_t>(v); break;
        case 8: x.layout = static_cast<uint8_t>(v); break;
        case 9: x.motor_ma = static_cast<uint32_t>(v); break;
        case 10: x.battery_ma = static_cast<uint32_t>(v); break;
        case 11: x.regen_ma = static_cast<uint32_t>(v); break;
        case 12: x.brake_ma = static_cast<uint32_t>(v); break;
        case 13: x.undervoltage_cv = static_cast<uint16_t>(v); break;
        case 14: x.overvoltage_cv = static_cast<uint16_t>(v); break;
        case 15: x.timeout_ms = static_cast<uint16_t>(v); break;
        case 16: x.timeout_brake_ma = static_cast<uint32_t>(v); break;
        case 17: x.reversal_erpm_limit = static_cast<uint16_t>(v); break;
        case 18: x.reversal_dwell_ms = static_cast<uint16_t>(v); break;
    }
}

bool isSet(const CommissioningProfile& p, uint8_t id, uint8_t w) {
    const Spec* s = specFor(id);
    if (!s) return false;
    const uint32_t mask = s->wheel ? p.wheel[w & 1].set_mask : p.set_mask;
    return (mask >> id) & 1u;
}

bool fieldOk(const CommissioningProfile& p, uint8_t id, uint8_t w) {
    const Spec* s = specFor(id);
    if (!s || !isSet(p, id, w)) return false;
    const int32_t v = rawGet(p, id, w);
    if (id == 5) return v == 1 || v == -1;
    return v >= s->lo && v <= s->hi;
}

bool allOk(const CommissioningProfile& p, const uint8_t* ids, size_t n, uint8_t w) {
    for (size_t i = 0; i < n; ++i) if (!fieldOk(p, ids[i], w)) return false;
    return true;
}

bool has(const CommissioningProfile& p, uint8_t bit) { return (p.acceptance >> bit) & 1u; }

const uint8_t kServoIds[] = {0, 1, 2};
const uint8_t kAutoIds[] = {3, 19, 20};
const uint8_t kConfigIds[] = {6, 7, 8, 9, 10, 11, 12, 13, 14};
const uint8_t kBrakeIds[] = {15, 16};
const uint8_t kDirIds[] = {5};
const uint8_t kRevIds[] = {17, 18};

bool servoOrdered(const CommissioningProfile& p) {
    return p.servo_min < p.servo_neutral && p.servo_neutral < p.servo_max;
}
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

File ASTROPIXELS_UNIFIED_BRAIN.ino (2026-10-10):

/*
 * ═══════════════════════════════════════════════════════════════════════════════
 *                    HISTORICAL REFERENCE ONLY: LEGACY ESP32 SKETCH
 *         (Superseded by TEENSY_BODY_CONTROLLER / ASTROPIXELS_PLUS_UNIFIED)
 * ═══════════════════════════════════════════════════════════════════════════════
 *
 * NOTE: This single-board sketch is retained for historical/engineering reference
 * only. The approved build uses the Teensy 4.1 body controller for real-time drive,
 * receiver decoding, dome servo pulses, and audio, while ASTROPIXELS_PLUS_UNIFIED
 * runs on the dome ESP32 for lighting, holo servos, and Wi-Fi diagnostics.
 *
 * ═══════════════════════════════════════════════════════════════════════════════
 *                    R2-D2 UNIFIED ASTROPIXELS DOME BRAIN (LEGACY)
 *         (ESP32 Master Brain: Persistent Moods, Macros, Servos & Audio)
 * ═══════════════════════════════════════════════════════════════════════════════
 *
 * Board:          ESP32 Dev Module (30-pin, AstroPixels Motherboard)
 * Architecture:   Deterministic, Non-Blocking, Zero-Heap Allocation State Machine
 *
 * Implemented Subsystems & Engineering Protections:
 *   1. Hardware UART2 (115,200 baud / GPIO 16): Non-blocking i-Bus frame parser with CRC
 *   2. Hardware UART1 (9,600 baud / GPIO 17): Dedicated DFPlayer serial audio transmitter
 *   3. LEDC Hardware PWM (GPIO 4): 35kg 360° continuous dome servo with zero-creep sleep
 *   4. KY-003 Hall Effect Sensor (GPIO 5): Active 0° Home auto-alignment state machine
 *   5. PCA9685 I2C 16-Channel Controller: 6-servo HoloProjector posture & manual tilt override
 *   6. FastLED WS2812 Controller: FLD1/2, RLD, FPSI, RPSI, and 3x HP LED cores
 *   7. Dual-Layer Personality Engine: 5 Persistent Moods + 5 Interruptible Macros
 *
 * ═══════════════════════════════════════════════════════════════════════════════
 */

#include <Arduino.h>
#include <Wire.h>
#include <Adafruit_PWMServoDriver.h>
#include <FastLED.h>

// ═══════════════════════════════════════════════════════════════════════════════
// 1. PIN DEFINITIONS & HARDWARE CONSTANTS
// ═══════════════════════════════════════════════════════════════════════════════

// Serial Communication Pins (Decoupled UARTs for distinct baud rates)
#define PIN_IBUS_RX         16    // Hardware Serial2 RX (115,200 baud): FlySky i-Bus
#define PIN_SOUND_TX        17    // Hardware Serial1 TX (9,600 baud): Body DFPlayer RX

// Dome Drive & Homing Pins
#define PIN_DOME_SERVO_PWM  4     // LEDC PWM: 35kg 360° Dome Continuous Servo
#define PIN_DOME_HALL_SENS  5     // Digital Input (Pull-up): KY-003 Hall Sensor in Dome

// I2C Pins (PCA9685 Servo Controller)
#define PIN_I2C_SDA         21
#define PIN_I2C_SCL         22
#define PCA9685_I2C_ADDR    0x40

// FastLED WS2812 Pin Assignments
#define PIN_LED_FLD         15    // Front Logic Displays (daisy-chained FLD1 -> FLD2)
#define PIN_LED_RPSI        23    // Rear Process State Indicator
#define PIN_LED_FHP         25    // Front HoloProjector LED Core
#define PIN_LED_RHP         26    // Rear HoloProjector LED Core
#define PIN_LED_THP         27    // Top HoloProjector LED Core
#define PIN_LED_FPSI        32    // Front Process State Indicator
#define PIN_LED_RLD         33    // Rear Logic Display

// LED Pixel Counts
#define NUM_LEDS_FLD        80
#define NUM_LEDS_RLD        80
#define NUM_LEDS_FPSI       24
#define NUM_LEDS_RPSI       24
#define NUM_LEDS_HP         7     // 7 LEDs per HoloProjector core

// Static LED Buffers (Zero Dynamic Heap Allocation)
CRGB leds_fld[NUM_LEDS_FLD];
CRGB leds_rld[NUM_LEDS_RLD];
CRGB leds_fpsi[NUM_LEDS_FPSI];
CRGB leds_rpsi[NUM_LEDS_RPSI];
CRGB leds_fhp[NUM_LEDS_HP];
CRGB leds_rhp[NUM_LEDS_HP];
CRGB leds_thp[NUM_LEDS_HP];

// PCA9685 12-bit PWM Counts (50Hz = 20ms period, 4096 steps = 4.88us/step)
#define SERVO_MIN_PULSE     205   // ~1.00ms
#define SERVO_MID_PULSE     307   // ~1.50ms (Center)
#define SERVO_MAX_PULSE     410   // ~2.00ms

// 35kg Continuous Rotation Dome Servo (LEDC Channel 0, 16-bit resolution)
#define DOME_LEDC_CHANNEL   0
#define DOME_LEDC_FREQ      50    // 50Hz standard servo frequency
#define DOME_LEDC_RES       16    // 16-bit resolution (0-65535)
#define DOME_DUTY_STOP      4915  // ~1.50ms (Center Neutral)
#define DOME_DUTY_MAX_CW    6553  // ~2.00ms (Full CW)
#define DOME_DUTY_MAX_CCW   3276  // ~1.00ms (Full CCW)
#define DOME_CENTER_TRIM    0     // Fine-tune offset in duty ticks if servo drifts

// ═══════════════════════════════════════════════════════════════════════════════
// 2. STATE ENUMS & PROGMEM DATA STRUCTURES
// ═══════════════════════════════════════════════════════════════════════════════

// Layer 1: Persistent Ambient Moods (Governs continuous idle behavior)
enum PersistentMood : uint8_t {
  MOOD_NORMAL = 0,    // Iconic movie look, balanced chirps, periodic gentle wandering
  MOOD_HAPPY,         // Fast lively logics, frequent high-pitch whistling, rapid twitches
  MOOD_SASSY,         // Grumbling razzes, impatient dome shakes, orange/purple logics
  MOOD_SAD,           // Slow dim blue logics, dropped holos, mournful low whines
  MOOD_ALERT,         // Rapid red strobe, aggressive head sweeps, alarm klaxon pulses
  MOOD_COUNT
};
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

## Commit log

2026-09-02 Initial commit: Single ESP32 dome brain architecture baseline and documentation
    [Master_R2D2_BOM.xls]
2026-09-02 Implement production-grade ESP32 Dome Brain with persistent mood engine and zero-heap optimizations
2026-09-02 Apply master embedded fixes: Hardware UART decoupling (115.2k i-Bus / 9.6k Sound), dome servo zero-creep sleep, and dual PPM VESC integration
    [ASTROPIXELS_UNIFIED_BRAIN.ino]
2026-09-02 Integrate active 0° Home auto-alignment state machine with Hall sensor interrupt and chained Leia hologram macro
2026-09-03 Update Design C CAD visualizer for Ø100mm x 38mm wheel, 10mm mounting ears (58mm span), and 12mm ground clearance
    [app.js]
2026-09-04 Eliminate phantom dual-box rendering in Design C visualizer to show single unified 100mm x 38mm hub motor wheel with 10mm ears
2026-09-04 Generate 3D printable STL models and parametric OpenSCAD source for 16x11mm Double-D axle clamping mounts
    [Razor_Hub_Motor_Axle_Clamp_Bottom.stl, Razor_Hub_Motor_Axle_Clamp_Top.stl, Razor_Hub_Motor_Mount.scad]
2026-09-04 Update BOM Item 5 referencing generated 3D printable axle clamp STLs
    [Master_R2D2_BOM.xls]
2026-09-04 Generate precision high-resolution STLs with exact 16.2mm x 11.2mm Double-D pocket arcs, top mounting flange, and wire relief channel
    [Razor_Hub_Motor_Axle_Clamp_Bottom.stl, Razor_Hub_Motor_Axle_Clamp_Top.stl]
2026-09-04 Fix 80-byte header offset and regenerate 100% watertight, verified 2-manifold binary STLs via Marching Cubes
    [Razor_Hub_Motor_Axle_Clamp_Bottom.stl, Razor_Hub_Motor_Axle_Clamp_Top.stl]
2026-09-08 Generate 100% watertight 2-manifold Slotted Dropout Mount STL for Razor 100mm Hub Motor verified in BambuStudio
    [Razor_Hub_Motor_Slotted_Mount.stl]
2026-09-08 Generate 100% watertight 120mm Drop-in Motor Cradle STL verified by BambuStudio CLI
    [Razor_Hub_Motor_120mm_Cradle.stl]
2026-09-08 Update 120mm Motor Cradle STL with exact 16.2mm wide slot for 16mm long x 11mm tall D-shaft, plus bottom keeper insert
    [Razor_Hub_Motor_120mm_Cradle.stl, Razor_Hub_Motor_Bottom_Keeper.stl]
2026-09-08 Generate 120mm U-cradle with 11.2mm tall horizontal rear slot and semicircular capped end verified by BambuStudio
    [Razor_Hub_Motor_120mm_Cradle.stl]
2026-09-08 Purge all failed cradle and clamp files; retain only verified Razor_Hub_Motor_Slotted_Mount.stl
    [Razor_Hub_Motor_120mm_Cradle.stl, Razor_Hub_Motor_Axle_Clamp_Bottom.stl, Razor_Hub_Motor_Axle_Clamp_Top.stl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]
2026-10-07 Document R2 wiring and commissioning; integrate unified dome firmware
    Capture selected hardware, power harness and interactive wiring diagram, RC and macro safety fixes, and staged firmware and VESC commissioning. Record the user-selected unfused 5V distribution and remaining hardware verification limits.
    [Master_R2D2_BOM.xls]
2026-10-07 Add project overview and WIP Tekno Pop motor mounts
    [case_bottom_locators_only.stl, r2d2_clean_motor_mount.stl, r2d2_inboard_axle_keeper_plate.stl]
2026-10-09 Migrate receiver to dome and drive dual VESC via ESP32 UART over CAN
    - Relocate FlySky FS-iA6B receiver to dome with iBUS direct to ESP32 GPIO 16
    - Implement Dual VESC 4.20 UART packet transmission & tank mixing in ASTROPIXELS_PLUS_UNIFIED firmware via GPIO 18 (AUX 4) down Slip Ring CH6
    - Eliminate body microcontroller; utilize Flipsky internal CAN bus switch ('ON: dual') to command Slave (ID 2) from Master (ID 1)
    - Reassign Slip Ring CH3 as insulated spare
    - Update interactive wiring_visualizer.html and documentation (SYSTEM_ARCHITECTURE, DOME_WIRING_DIAGRAM, POWER_HARNESS_GUIDE, VESC_DRIVE_INTEGRATION, BOM)
    - Add unit tests for VESC packet generation, duty calculation, CAN forwarding, and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
    [Master_R2D2_BOM.xls]
2026-10-09 Add bidirectional VESC UART with telemetry and battery protection
    - Dedicate full-duplex Serial2 to VESC (TX GPIO18 down CH6, RX GPIO5 up CH3)
    - Move FlySky i-BUS to dedicated Serial1 (RX GPIO16) and sound to dedicated DfPlayerSerial (TX GPIO17)
    - Implement VESC COMM_GET_VALUES polling (5Hz) and non-blocking packet decoding in firmware
    - Add automatic motor cutoff for battery low-voltage (<10.5V) and hardware fault codes
    - Update wiring_visualizer.html, pin diagrams, and all documentation for active CH3 telemetry
    - Add unit tests for telemetry request/decoding and protection cutoffs (33 tests passing)
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2026-10-09 fix: validate commission operation payloads
    [Messages.h]
2026-10-09 fix: harden link recovery and require acceptance evidence
    [ConfigStore.cpp, ConfigStore.h, main.cpp]
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2026-10-09 fix: keep VESC brake available on stale telemetry and guarantee polls under control
    [VescLink.cpp]
2026-10-09 chore: checkpoint build plans and in-progress drive firmware
    Preserve physical documentation, BOM, wiring inspector, firmware plans, and the unreviewed Task 5 implementation for cross-machine continuation. Add portable progress records and an explicit resume c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
    [Master_R2D2_BOM.xls]
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2026-10-09 feat: add acknowledged audio playback and track catalog
    - Implement bidirectional DFPlayer Mini driver (DfPlayer.h, DfPlayer.cpp)
    - Enforce >=100ms command spacing and foreground/ambient priority
    - Non-blocking 3-second initialization and 500ms status polling
    - Request-correlated playback events (PlaybackStarted, Completed, Cancelled, Timeout)
    - Elapsed playback bookkeeping with pause/resume support
    - Seed track catalog metadata (config/tracks.csv) with completion guards
    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
    [tracks.csv]
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2026-10-10 refactor: delegate body hardware from AstroPixels to Teensy
    [Master_R2D2_BOM.xls]
2026-10-10 docs: update BOM status and clear legacy migration warnings
    - Mark all pending hardware components as acquired in Master_R2D2_BOM.xls
    - Update BOM radio channels note and dome controller migration status
    - Replace outdated target-wiring warnings with Safety Notices across all guides
    - Update SYSTEM_ARCHITECTURE.md to note completed firmware migration
    - Update BODY_CONTROLLER_COMMISSIONING.md and README.md build/OTA steps
    - Update ASTROPIXELS_PLUS_UNIFIED.ino headers to document split architecture
    - Add historical reference notices to legacy standalone sketches
    - Add track 11 to config/tracks.csv for dome-home macro
    [Master_R2D2_BOM.xls, tracks.csv]
2026-10-10 docs: add FlySky FS-i6X controller operator guide and labeled layout
    - Add CONTROLLER_OPERATOR_GUIDE.md with plain-language switch, dial, and stick descriptions
    - Include labeled layout illustration in docs/images/flysky_fs_i6x_layout.jpg and ASCII diagram
    - Document 13-position routine schedule for knob VrA and trigger switch SwC
    - Detail 500ms neutral stick arming handshake for safety switch SwA
    - Detail 3-speed rates (35%, 70%, 95%) on switch SwB
    - Document autonomous dome wandering behavior on switch SwD
    - Add safe power-on checklist and failsafe configuration
    - Cross-link guide in README.md, SYSTEM_ARCHITECTURE.md, and VESC_DRIVE_INTEGRATION.md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
2026-10-10 docs: add pixel-accurate SVG vector layout and correct VrA/VrB pointer positions
    - Add docs/images/flysky_fs_i6x_layout.svg with exact physical coordinates for all dials and switches
    - Correct VrA and VrB pointer arrows to point to the top-center rotary knobs
    - Update CONTROLLER_OPERATOR_GUIDE.md to embed vector layout diagram
2026-10-10 docs: clarify single-vs-dual Hall sensor discrepancy in historical ESP32 guide
    - Add callout explaining that the historical FastLED sketch used a single Hall sensor
    - Direct builders to DOME_WIRING_DIAGRAM.md and SYSTEM_ARCHITECTURE.md for the approved dual-Hall architecture
2026-10-10 docs: streamline user guides, remove meta-language, and add VESC tuning guide
    - Remove 'plain language' meta-labeling from controller guide and documentation links
    - Remove conversational asides, historical deprecation references, and weasel words
    - Clarify fuse sizing as best estimates based on planned subsystem draw
    - Add practical VESC Tool configuration guide with 20A power budget breakdown
    (allocating 6-7A battery max per motor, leaving 5-6A headroom for auxiliary systems)
    - Provide concrete baseline settings for current limits, voltage cutoffs, and UART timeout
2026-10-10 docs: clarify PCA9685 3-pin servo headers and plug connections
    - Explicitly document that all 6 holoprojector servos plug directly onto
    the PCA9685 3-pin channel headers (Channels 0-5: PWM, V+, GND)
    - Clarify that the green screw terminal is exclusively for the main 16AWG
    power feed from the D-SERVO 5A fuse and ground return
    - Confirm that no servo power or ground is spliced into shared screw terminals
2026-10-10 Fix protocol reboot session, VESC renewal timing, build & test discrepancies
    - Fix Dome-Body protocol reconnection bug by advancing boot session in BodyController::init() and validating NVS writes in ASTROPIXELS_PLUS_UNIFIED
    - Loosen DriveController renewal deadline miss threshold to 50ms and relax watchdog starvation latch in BodyController
    - Smooth DriveController stick deadband outside 1460-1540us to eliminate low-speed step discontinuity
    - Fix PlatformIO compile errors in ASTROPIXELS_PLUS_UNIFIED (WebPages lock_reasons, startDomeHoming signature, EventKind/Completion enum alignment)
    - Pin Adafruit_NeoPixel to v1.12.4 and remove redundant FastLED dependency
    - Guard Watchdog_t4 for Teensy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
    [ASTROPIXELS_PLUS_UNIFIED.ino, BodyController.cpp, WebPages.h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]
2026-10-10 Fix body/dome integration: lock release, VESC polling, commissioning, dome link
    Teensy body controller
    - STOP/RELEASE/UNLOCK/RECOVER now clear the drive and dome latches: subsystem
    latches are released with their own epochs and releases are all-or-nothing
    behind the CH6 OFF / sticks-centred gate (refusals return NotReady).
    - VESC: identical brake renewals go out every 20ms instead of every loop pass,
    so stationary braking no longer starves GET_VALUES polls.
    - Actuators run the saved profile only; Save (USB or wireless) activates it and
    reloads the VESC links without a reboot. New `profile accept <bit>` CLI.
    - Commissioning: Neutral test completes after a 3s observation window; Accept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
    [ASTROPIXELS_PLUS_UNIFIED.ino, BodyClient.cpp, BodyController.cpp]
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2026-10-10 feat(commissioning): WheelTest state machine for timeout-brake, direction and reversal
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2026-10-10 feat(dome): auto dome waits for a CH9 flip after a Save enables it
    [BodyController.cpp, DomeController.cpp]
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2026-10-10 fix(dome): pace accept-and-save sends; commissioning page polish
    [ASTROPIXELS_PLUS_UNIFIED.ino, WebPages.h]
2026-10-10 fix(commissioning): browser keepalive for wheel tests and dome-side safety fixes
    - /drive runs a hidden heartbeat element (setInterval -> fetchNoload every
    150 ms); the dome forwards Keepalive for a wheel test (6-8) only while the
    last heartbeat is <= 500 ms old. Dome tests keep the dome-driven keepalive.
    Decision lives in CommissionKeepalive.h (BrowserHeartbeat,
    commissionKeepaliveAllowed).
    - Radio check: stick prompts say "With SwA UP" and count only while
    CH6 < 1250; SwD prompt warns a saved auto dome may turn; SwB macros are
    suppressed while the check prompts (a SwB still DOWN needs a fresh flip).
    - ProfileMirror forgets every cached field while the link is down.
    - Commission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
    [ASTROPIXELS_PLUS_UNIFIED.ino, WebPages.h]
2026-10-10 fix(commissioning): CLI profile set through the commission path; duty cap in commissioning mode
    - `profile set` now builds a SetField CommissionRequest and goes through
    calibration_.handleRequest, so it gets the Busy and stationary gates and
    no longer needs CH9 OFF. CH9 dropped from the set/accept refusal texts.
    - VescLink::dutyPermitted refuses |duty| > 100 permille whenever
    commissioning mode is on, even for a control-accepted wheel.
    [BodyController.cpp, VescLink.cpp]
2026-10-10 fix(config): a VESC limit change withdraws all of that wheel's test sign-offs
    Direction and reversal evidence covers fields 6-14, so changing one now
    clears those bits too, not only VESC config and timeout.
    [ConfigStore.cpp]
2026-10-10 feat(dome): live status on the commissioning pages
    /cstatus returns the status lines as text; /commissioning and /drive poll
    it and update in place, so no reload is needed while a test runs. A poll
    from /drive is the wheel-test browser heartbeat (replaces WHeartbeat).
    [WebPages.h]
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2026-10-11 feat(dome): FlySky remote features on stock AstroPixelsPlus
    Receiver iBUS on Serial2 (GPIO16) drives:
    - dome servo on GPIO4: stick always wins; random moves with SwA, homed on
    the front Hall sensor (GPIO5); driving sends the dome home
    - mood sounds: VrA picks a bank, SwB plays one, chatter follows the mood
    - volume on VrB, saved for the next power-up
    - random holo servo twitches, off with SwC up
    Stock changes, marked HDR2D2: holo servos on PCA9685 0x40 channels 0-5,
    DFPlayer always on and played by filename from /mp3, Marcduino serial
    input off, library versions pinned. Logic in R2Logic.h is host-tested.
2026-10-11 docs: guides for the simplified droid
    README, controller guide (channel map, Elevon, failsafe), drive setup
    (VESC receiver-input proof, second-half solder mod, VESC Tool settings,
    wheels-up tests), signal wiring (slip ring, dome shifter, Hall, PCA9685,
    DFPlayer) and dome firmware notes (flash, SD layout, serial log). Power
    guide and BOM updated: Teensy, carrier and rear Hall marked unused.
2026-10-11 docs: full documentation set for the simplified droid
    Plain, declarative guides: bring-up checklist, power, wiring, transmitter
    setup, drive setup, dome setup, sound setup, operating guide,
    troubleshooting and firmware reference. README maps the set and notes
    the two maintained designs.
    Random dome moves to CH5 (SwA) so the receiver failsafe can switch it
    off; play-sound, mood and volume move to CH6-CH8.
2026-10-11 fix(dome): review fixes for the remote add-on
    - DFPlayer ACKs off after start-up: commands cost 10ms instead of
    blocking the loop up to 500ms
    - front Hall sensor latched by interrupt so a pass is never missed
    - dome servo pin held low from the start of setup()
    - driving detected at 40us, inside the VESC's 10% deadband
    - Wi-Fi and the ESP-NOW droid remote off by default (#APWIFI1 turns
    Wi-Fi on)
    - chatter interval honours the stock random min/max settings
2026-10-11 docs: review fixes
    - wheel direction set in VESC Tool (positive duty = forward); mix
    direction fixed with transmitter Reverse / Elevon AIL sign; no lead
    swapping, so CH1 is always half A (left) and CH2 half B (right)
    - centre-stick braking test added, with the PID Speed fallback
    - Hall sensor and magnet placement matches the BOM
    - Wi-Fi off by default: how to turn it on and change the password
    - firmware doc lists which stock web settings still apply
    - BOM: SD card layout, magnet, half-B servo lead, stale Teensy/UART text
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2026-10-11 docs(vesc): FSESC4.20 pinout reference
    Every connector and pin on the 4.20 (CAN, SENSE, COMM, SWD, USB,
    receiver input), the dual board differences and CAN switch, the shared
    5 V budget, and which pins this build uses. Explains that the VESC
    "PPM" app reads the receiver PWM output. Adds the Flipsky wiring sheet
    photo the pin labels come from.
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2026-10-11 chore: serve the repository on GitHub Pages as plain files
    .nojekyll stops the Jekyll build, which fails on the GitBook tags in
    docs/astropixels. The wiring reference links to the rendered guides on
    GitHub so they read correctly from Pages.
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2026-10-11 feat: build hub home page for GitHub Pages
    index.html is now a home page linking the wiring reference, the drive
    visualizer and every guide. The foot-drive visualizer moves to
    drive_visualizer.html (with drive_visualizer.js/.css) and both tools
    link back home. A test checks every site link resolves.
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2026-10-11 docs(spec,plan): holo ranges from the servo table, no calibration
    Holo eyes map onto each servo's row in the servo table with ReelTwo's
    0..1 moveTo, as ReelTwo's own holo code does. Per-axis flips cover
    mechanisms mounted the other way round.
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2026-10-11 feat(dome): track the dome angle from a ring of body magnets
    Each blip is the next magnet in the direction of travel; a short gap
    marks the front pair. Speeds are learned per direction and servo offset
    band and used to estimate the angle between magnets. Missed or extra
    magnets are caught at the front pair or by overdue travel.
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2026-10-11 feat(dome): attention planner for looks, sounds and gestures
    Looks are queued as steps: notice sound, front-eye lead, dome turn,
    hold with a readjust, double-take, glance or comment, an optional
    chained look, then return. Stick, driving, SwB and the Still/Aware/
    Alive levels interrupt with the spec's priorities. Two failed seeks
    disable the dome until Still.
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2026-10-11 fix(dome): tracking and motion robustness found by the simulation
    - a reversal inside the front pair, or just past it, keeps the position
    - a short gap only confirms front where the count expects the pair;
    elsewhere the position is dropped and re-found by a seek
    - the first gap after front is learned
    - before speeds are learned, a jammed dome is still caught (6 gaps)
    - while the estimate is held short of a magnet, moves creep on to the
    magnet instead of arriving early, then speed up again
    - moves to a magnet (every return to front) end only on that magnet
    - test simulator: a slice ending exactly on a magnet still blips
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2026-10-11 fix(dome): blips and commands reach the tracker in time order
    A Hall interrupt landing between the loop's blip read and its tracker
    update gave the tracker a blip older than its clock: the unsigned gap
    wrapped to 4295 s of travel, which then read as a front-pair baseline.
    - The tracker's clock never runs backwards.
    - r2::drainBlips() reads blips up to one micros() snapshot per pass and
    drops the position when the 8-entry ring overflowed. R2Remote uses the
    same snapshot for update() and setCommand().
    - A previous gap more than 2.5x the one before it (a stall or lost blips)
    is no longer a baseline for front-pair detection. A stalled dome that
    freed itself used to fake a front.
    Co-Aut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
2026-10-11 fix(dome): a reversal over a magnet keeps that magnet
    A Hall switch reads low across an arc around each magnet and blips once,
    on entry. A dome that stopped inside the arc of the magnet it just
    reported (every magnet-confirmed return to front does) gets no new blip
    when it backs off, so shifting the count at the reversal put it one
    magnet out.
    R2Remote passes the sensor level to the tracker each pass. Over a magnet,
    a reversal keeps it as the last magnet passed. The test simulator now
    models the detection arc and an optional speed lag.
2026-10-11 fix(dome): speed estimates follow the learned speeds
    Only the 40 us seek band was learned after 17 simulated minutes, and
    offsets elsewhere were scaled through zero from it, about 20% fast at
    cruise. The estimate then reached each magnet early, DomeMotion crept
    mid-cruise, and no cruise band was ever steady enough to learn.
    - Unlearned offsets interpolate between learned speeds (spec §4). Beyond
    them the line runs to the zero-speed offset, learned from two speeds
    40 us apart (default 20 us).
    - Each band keeps the offset its speed was measured at (DomeSpeeds; the
    saved blob grows to 464 bytes).
    - A band one direction hasn't learned uses the other direction's.
    - A held estimate makes t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
2026-10-11 fix(dome): moves stop on target, not at speed
    - Ease times stretch to what the 10 us per 20 ms step limit can follow:
    the sine ramp's steepest part is pi/2 times its average slope. Happy's
    0.35 s, the wiggle's 0.2 s and the 1.5x glances outran the step limit,
    so braking started too late.
    - A move arrives only once the pulse is down at the final-approach speed.
    A target that lands just ahead of a fast dome (a gesture or return
    starting mid-move) brakes on and comes back if passed by more than 6 deg.
2026-10-11 test(dome): virtual droid on a dome shaped like the real one
    The virtual droid now runs R2Remote's loop pass for pass on a simulated
    dome with a 1 degree Hall arc per magnet, 40 ms speed lag and a 15 us
    deadband. Blips go through an 8-entry ring and drainBlips(). It covers every
    level and every mood plus Mixed, with SwB, driving, stick turns, a Still
    flip and radio loss.
    Checks use the spec's numbers: tracking within 5 degrees after five
    minutes, every return resting within 3 degrees of front, no lost position,
    step limit, sound gaps, and Still and Aware never moving the dome on their
    own. Against the pre-fix headers this run loses the position 6-14 times
    per 30 minutes and rests up to 90 d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
2026-10-11 docs: match the fixed dome behaviour; BOM magnets to order
    - Leaving Alive finishes a look at front; a stick-turned dome stays put
    (Operating Guide, Dome Setup, failsafe table).
    - The first look starts the slow find-front turn; a failed find is two
    ~22 s turns a look apart; a slow circle between looks means a lost count.
    - Sad's gesture is a 45 degree turn; every gesture ends facing front;
    Whistle glances toward front during a look.
    - Holo looks can reach both ends of the servo range.
    - HDR2D2.md: Hall level read, saved speed format, tracker tuning, and
    what the virtual droid test covers.
    - BOM: 12 more magnets to order.
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
